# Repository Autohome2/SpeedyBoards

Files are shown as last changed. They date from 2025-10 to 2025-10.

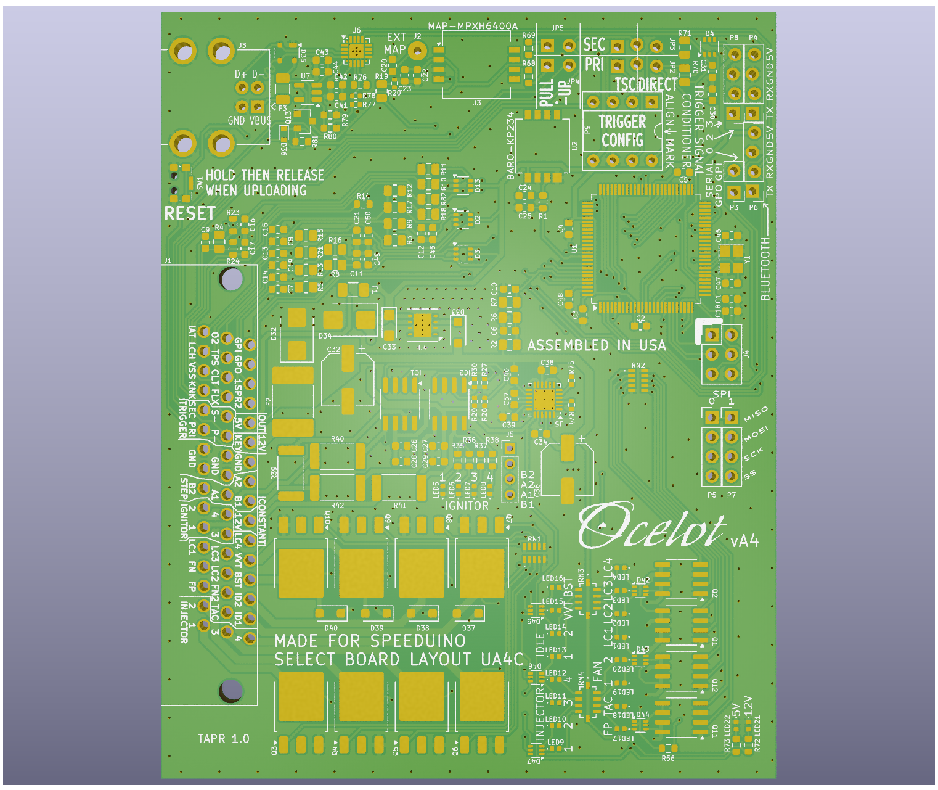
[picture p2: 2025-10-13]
OCELOT/Ocelot-vA4/RENDER/3D-Top.png

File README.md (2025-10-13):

# SpeedyBoards
WTMtronics has developed several EMS PCBs designed to use the Speeduino firmware.
The Speeduino code is available here [Speeduino](https://github.com/noisymime/speeduino), but the easiest way to load the code onto your ECU is to use [SpeedyLoader](https://github.com/speeduino/SpeedyLoader).
## Ocelot
The latest ECU designed by WTMtronics builds on the UA4C that came before it, and in fact if you compare the two side by side you will see many similarities. However there have been many improvements over the previous model which are outlined in the list below.
- Automotive connector
- Reduced size
- Integrated microcontroller
- VSS input
- Flyback diodes
- Reset button

The reset button was added as the only reset connection made to the microcontroller to prevent unwanted resets from USB connected devices. There is a caveat to this arrangement though. While the first time a firmware is loaded it will go on without intervention, subsequent times will require the user to hold the reset button down then release the button when the program starts the upload process. If the upload does not start right away go back and try again.

The Ocelot uses the Silicon Labs CP2102N USB to UART controller chip. Most modern computers will detect and automatically load a driver for the COM port. If you are not getting the COM port, then you can download drivers from their website [Silicon Labs Drivers](https://www.silabs.com/developers/usb-to-uart-bridge-vcp-drivers).

Versions:

A4:
- Corrected USB chip power
- Changed to smaller USB chip
- Corrected trigger labeling
- Changed trigger jumpers to match other boards

A3:
- First release

### Errata
vA3:
- Labeling for trigger jumpers is reversed. The secondary trigger jumpers are nearest the outside edge of the board, and the primary trigger jumpers are near the trigger conditioner socket.
- Serial numbers prior to 002287 will not operate with out a USB connection if no Bluetooth adapter is attached. If your serial number is 002287 or higher this issue does not affect your unit. If you are affected by this issue, please contact us so we can help you [WTMtronics Help](https://wtmtronics.com/help).
## UA4C
The Under Arduino Four Channel was designed to be as small as possible wile still using a standard off the shelf Arduino MEGA and Hammond extruded enclosure. This was achieved by using SMD components and placing the Arduino upside-down on top of the PCB. The unique stacking arrangement allows the unit to be particularly thin for a unit that still uses a separate Arduino MEGA. It is a 4+4 board that incorporates the follow features.
- Four injector channels
- Four ignitor channels
- Outputs for VVT, 2x PWM idle, boost, fuel pump, tachometer, and 2x fan
- Four auxiliary outputs
- Built in stepper idle control (versions C)
- Two trigger inputs
- Launch input
- Two additional interrupt input designated as flex and knock*
- Analog inputs for CLT, IAT, TPS, and O2
- Two auxiliary analog inputs
- MAP and baro sensor onboard
- Two GPIO connections that breakout inside the case

Latest version: C6

*Knock is currently unsupported in the firmware. Either input can be used for VSS.
## NO2C
The No Overhang Two Channel was designed to incorporate as many features as possible into a through-hole board that does not exceed the dimensions of the Arduino MEGA microcontroller it sits on top of. It is a 2+2 channel board that incorporates the features below.
- Two injector channels
- Two ignitor channels
- Outputs for VVT PWM idle, boost, fuel pump, and tachometer
- Two trigger inputs
- Launch input
- Analog inputs for CLT, IAT, TPS, and O2
- MAP sensor onboard
- Socket for stepper idle control module

Latest version: D1

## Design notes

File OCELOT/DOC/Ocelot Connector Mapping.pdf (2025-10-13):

All outputs (except ignitor and stepper idle) are ground switching. Connect at least two ground terminals to a single ground source.
Connector Terminal | Arduino Pin | Function
1 | | GPI | 25 | | STEPPER IDLE A1
2 | | GPO | 26 | D34 | IGNITOR 4
3 | A8 | SPARE INPUT 1 | 27 | D33 | IGNITOR 3
4 | A9 | SPARE INPUT 2 | 28 | D28 | LOW CURRENT OUTPUT 3
5 | | 5V OUT | 29 | D27 | LOW CURRENT OUTPUT 2
6 | | KEYED 12V INPUT | 30 | D25 | FAN 2
7 | | GROUND | 31 | D22 | TACHOMETER
8 | | STEPPER IDLE A2 | 32 | D6 | INJECTOR 3
9 | | STEPPER IDLE B1 | 33 | A5 | INLET AIR TEMPERATURE SENSOR
10 | | UNSWITCHED 12V INPUT (FLYBACK FOR IDLE, BOOST, VVT) | 34 | D37 | LAUNCH/CLUTCH
11 | D29 | LOW CURRENT OUTPUT 4 | 35 | D2 | VEHICLE SPEED SENSOR
12 | D11 | VVT | 36 | D21 | KNOCK SENSOR
13 | D12 | BOOST | 37 | D18 | SECONDARY TRIGGER
14 | D10 | PWM IDLE 2 | 38 | D19 | PRIMARY TRIGGER
15 | D9 | PWM IDLE 1 | 39 | | GROUND
16 | D5 | INJECTOR 4 | 40 | | GROUND
17 | A1 | EXHAUST GAS SENSOR | 41 | | STEPPER IDLE B2
18 | A3 | THROTTLE POSITION SENSOR | 42 | D36 | IGNITOR 2
19 | A4 | COOLANT TEMPERATURE SENSOR | 43 | D35 | IGNITOR 1
20 | D20 | FLEX FUEL SENSOR | 44 | D26 | LOW CURRENT OUTPUT 1
21 | | SECONDARY TRIGGER (VR- ONLY) | 45 | D24 | FAN 1
22 | | PRIMARY TRIGGER (VR- ONLY) | 46 | D23 | FUEL PUMP
23 | | GROUND | 47 | D7 | INJECTOR 2
24 | | GROUND | 48 | D8 | INJECTOR 1
1 | 2 | 3 | 4 | 5 | 6 | 7 | 8 | 9 | 10 | 11 | 12 | 13 | 14 | 15 | 16
17 | 18 | 19 | 20 | 21 | 22 | 23 | 24 | 25 | 26 | 27 | 28 | 29 | 30 | 31 | 32
33 | 34 | 35 | 36 | 37 | 38 | 39 | 40 | 41 | 42 | 43 | 44 | 45 | 46 | 47 | 48

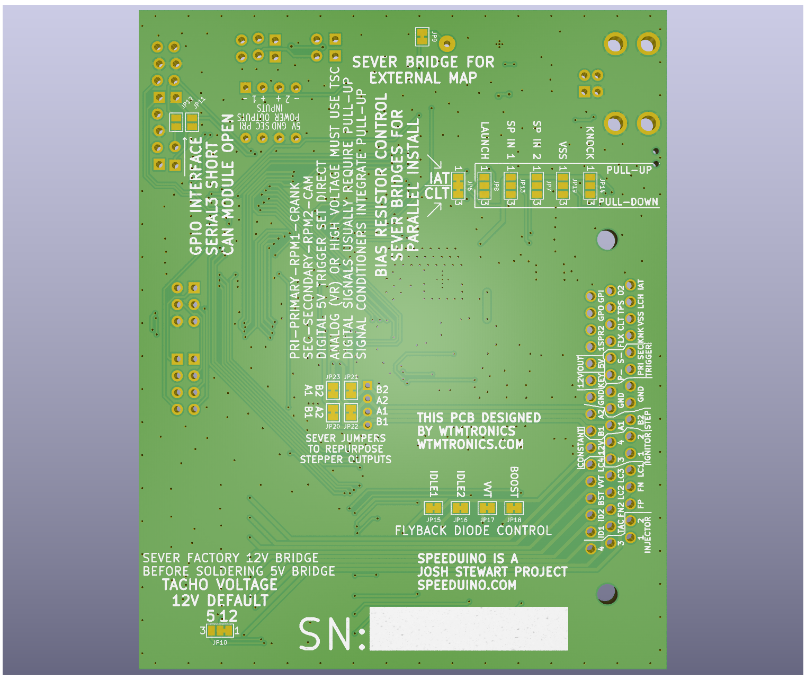
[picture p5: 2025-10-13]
OCELOT/Ocelot-vA4/RENDER/3D-Bottom.png

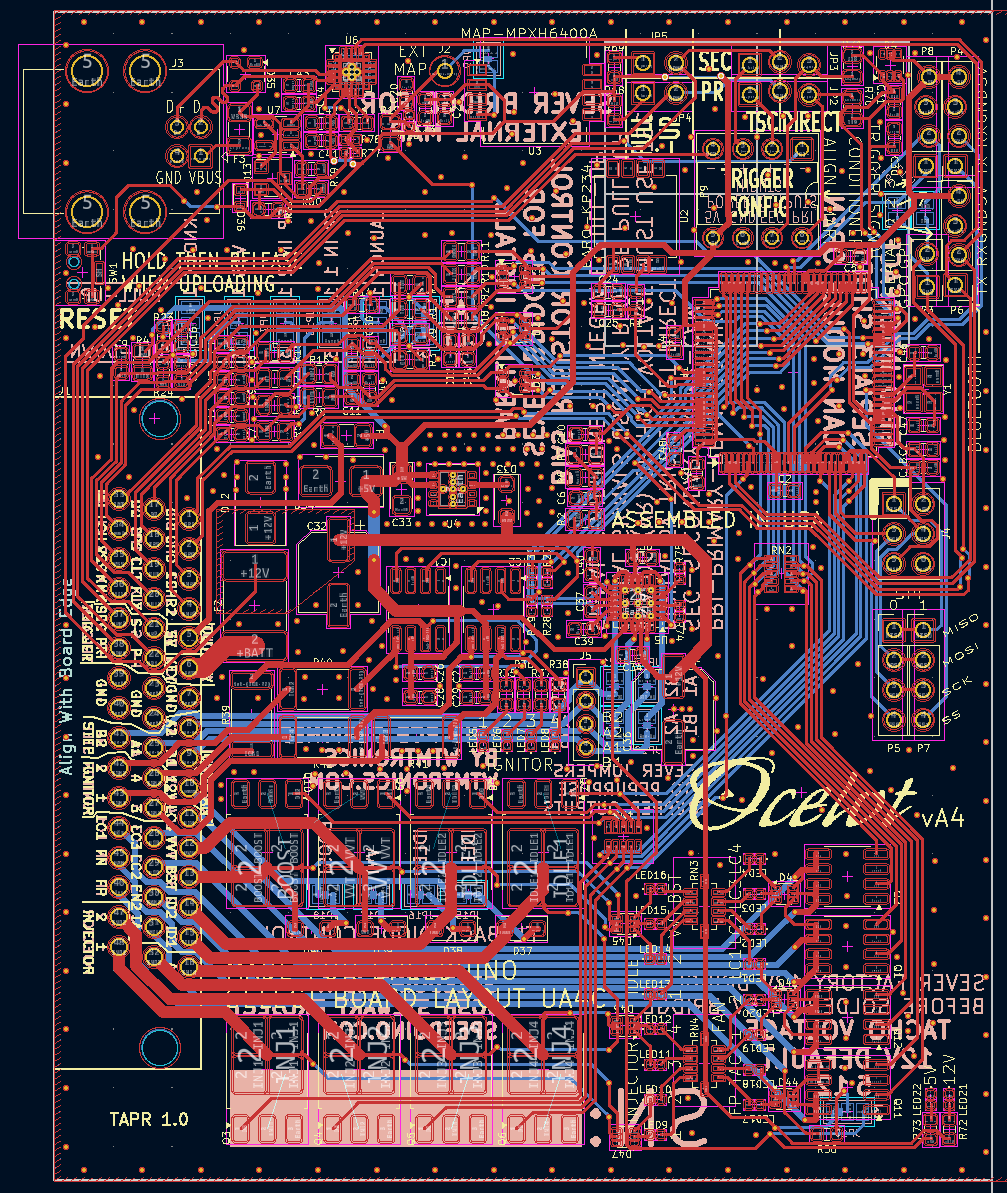
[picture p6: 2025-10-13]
OCELOT/Ocelot-vA4/RENDER/CAD.png

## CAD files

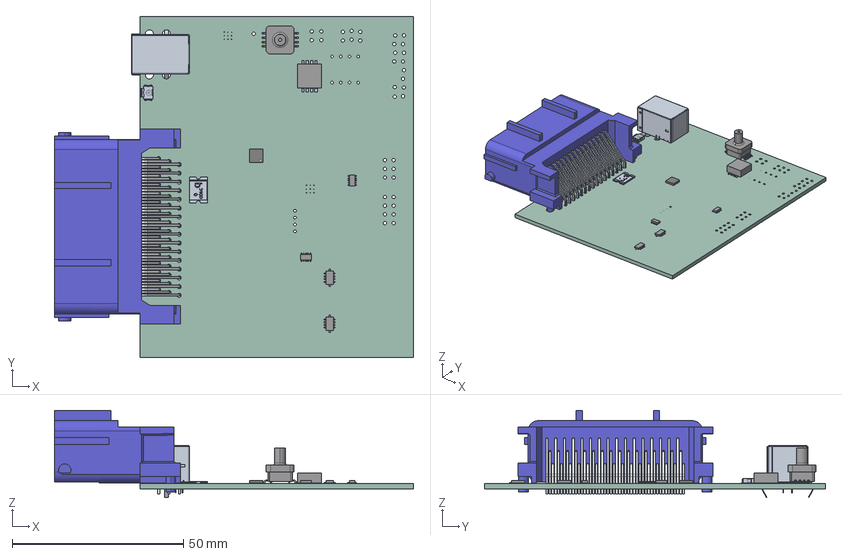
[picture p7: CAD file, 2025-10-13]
OCELOT/Ocelot-vA3/Ocelot-vA3.step
105.0 x 99.8 x 25.5 mm
MPXH6400AC6T1
100-60 v1
WSON8_4x4mm_Pitch08mm
HPppfj48PAZu_100525
ASSEMBLY x 5
OCELOT-vA3_PCB

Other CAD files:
OCELOT/Ocelot-vA3/ocelot.step

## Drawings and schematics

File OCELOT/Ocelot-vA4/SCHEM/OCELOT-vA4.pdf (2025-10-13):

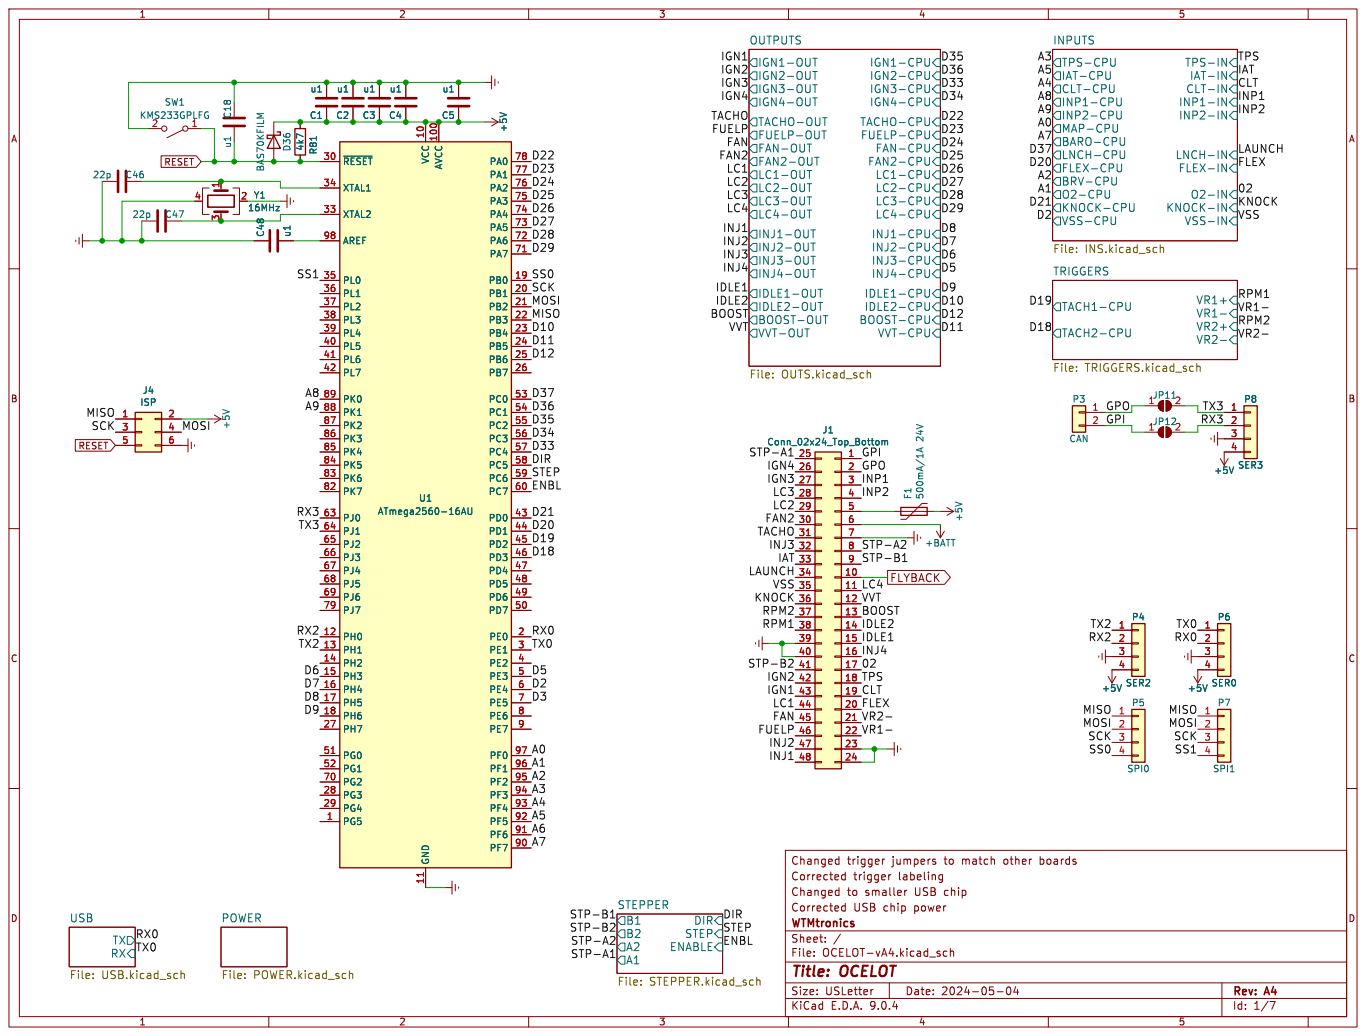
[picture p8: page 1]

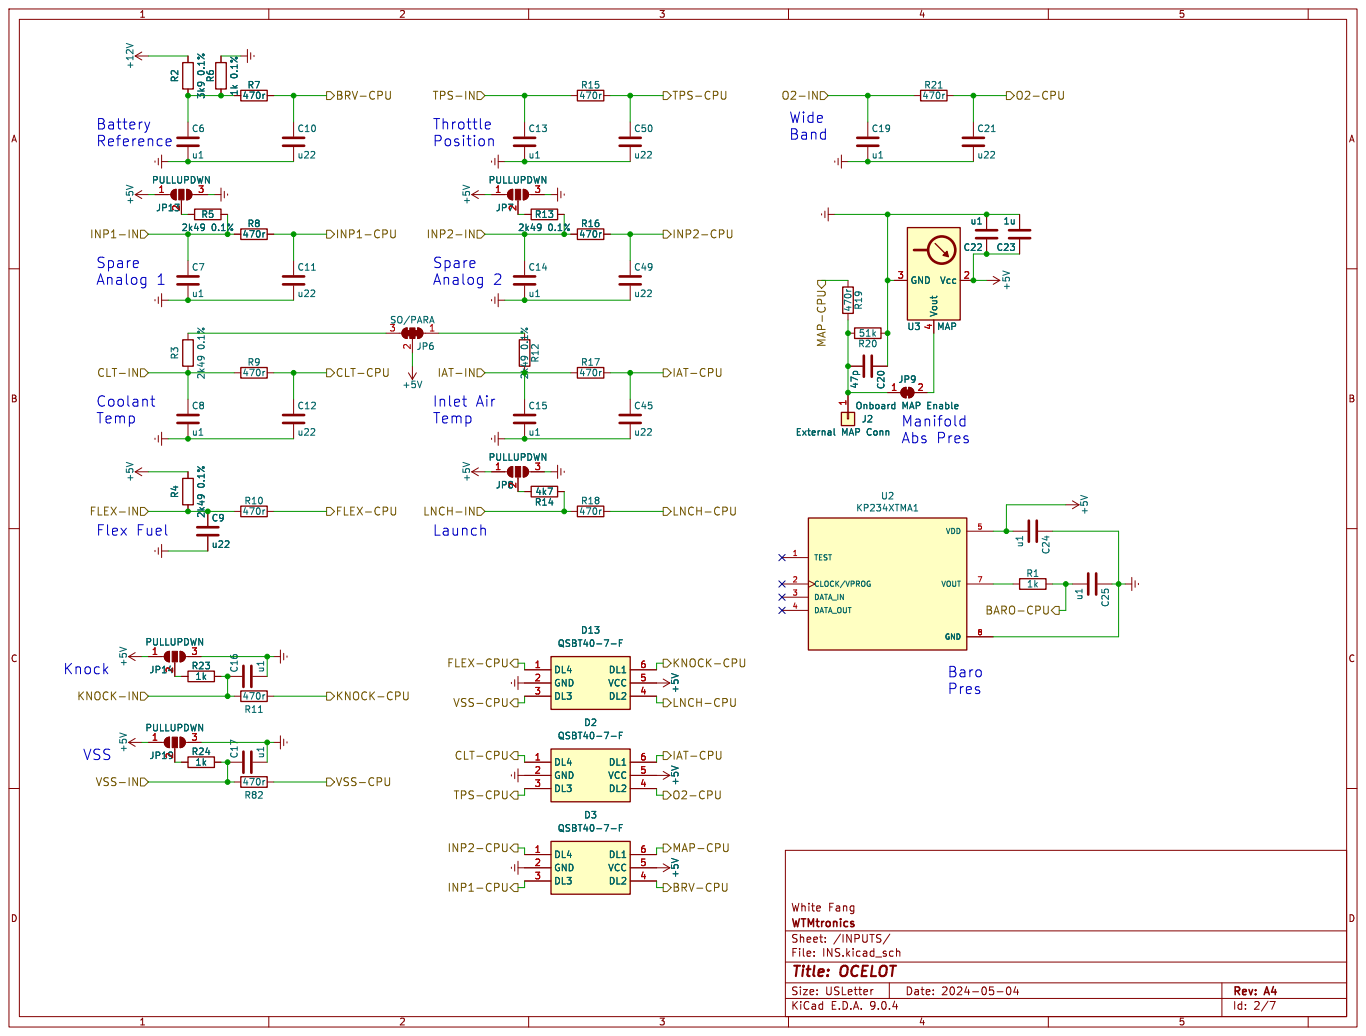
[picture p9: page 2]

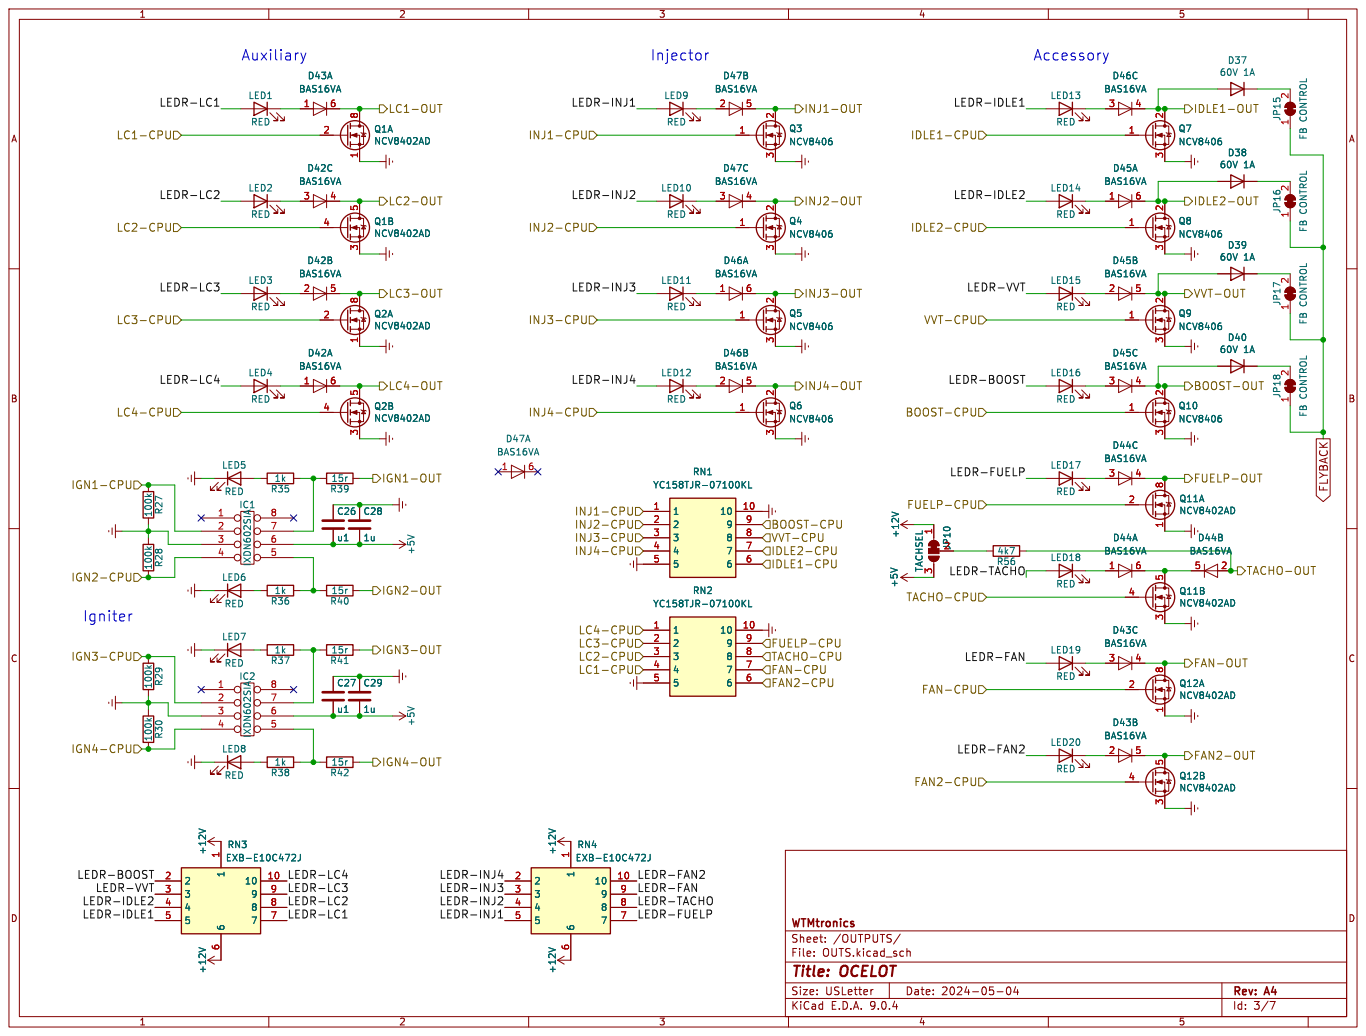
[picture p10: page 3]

File: OUTS.kicad_sch Sheet: /OUTPUTS/ WTMtronics

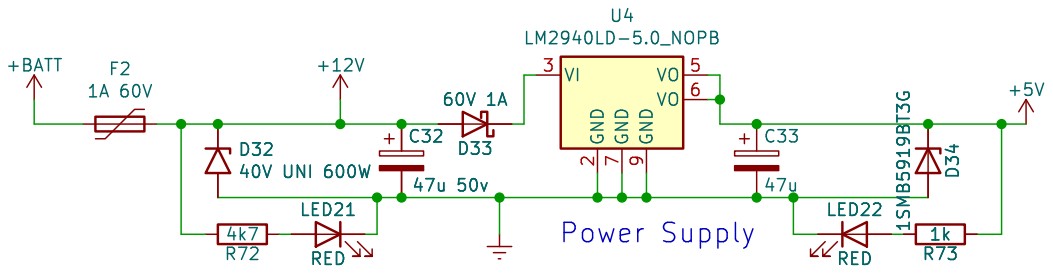
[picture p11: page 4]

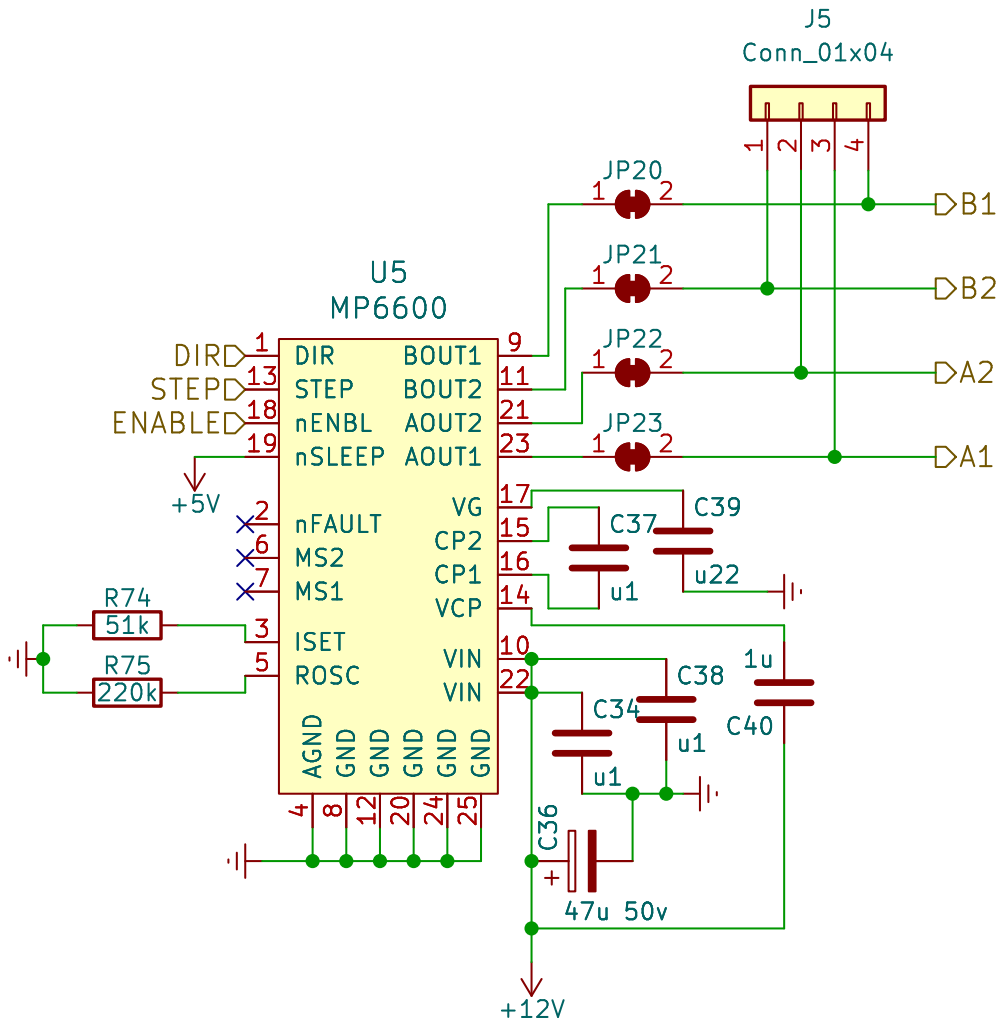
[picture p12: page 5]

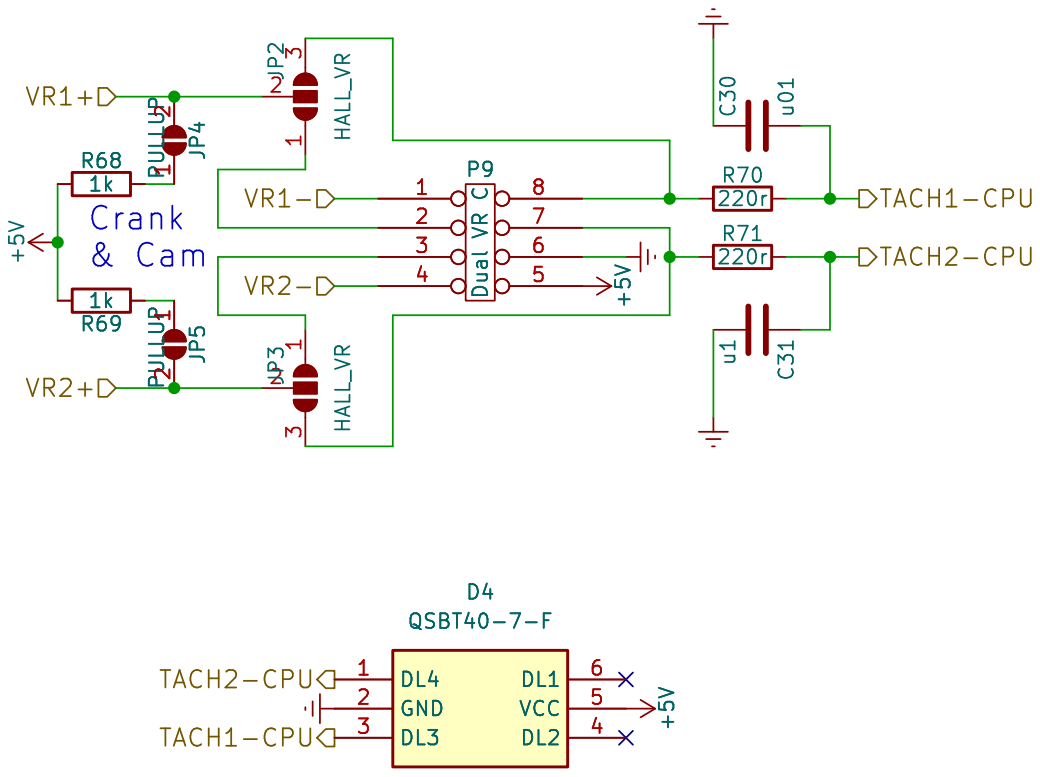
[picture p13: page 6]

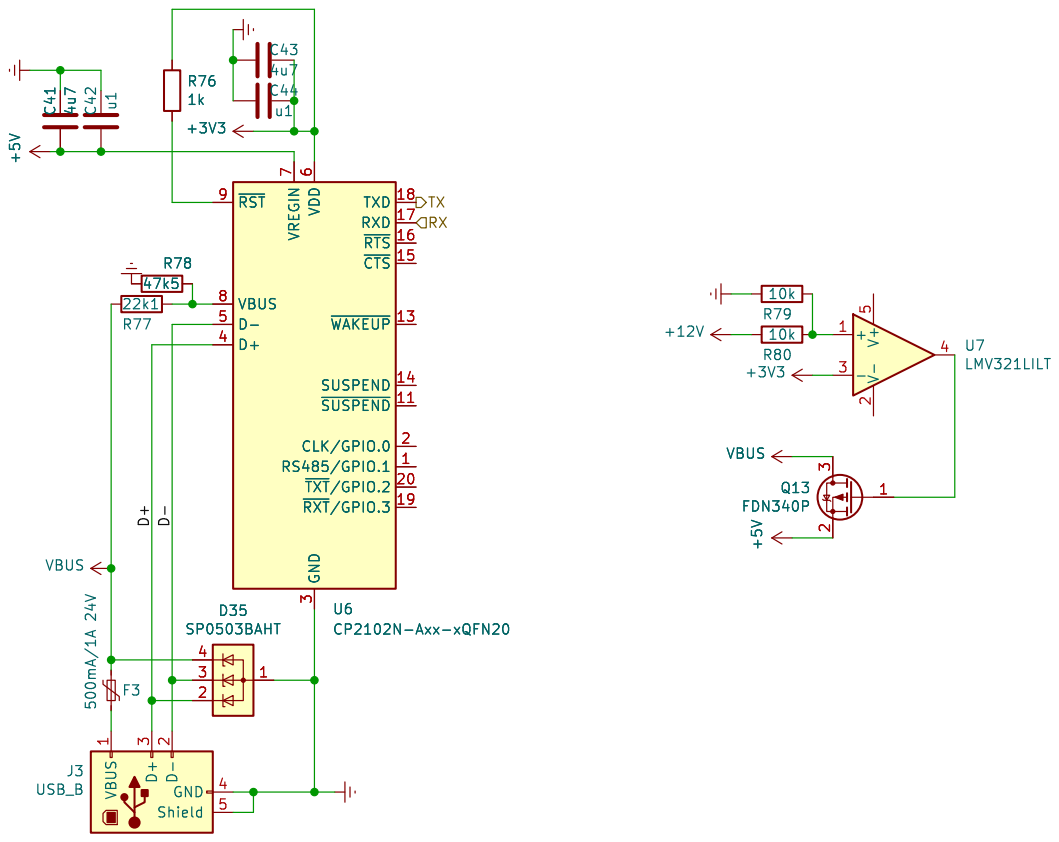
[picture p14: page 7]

File: USB.kicad_sch Sheet: /USB/ WTMtronics

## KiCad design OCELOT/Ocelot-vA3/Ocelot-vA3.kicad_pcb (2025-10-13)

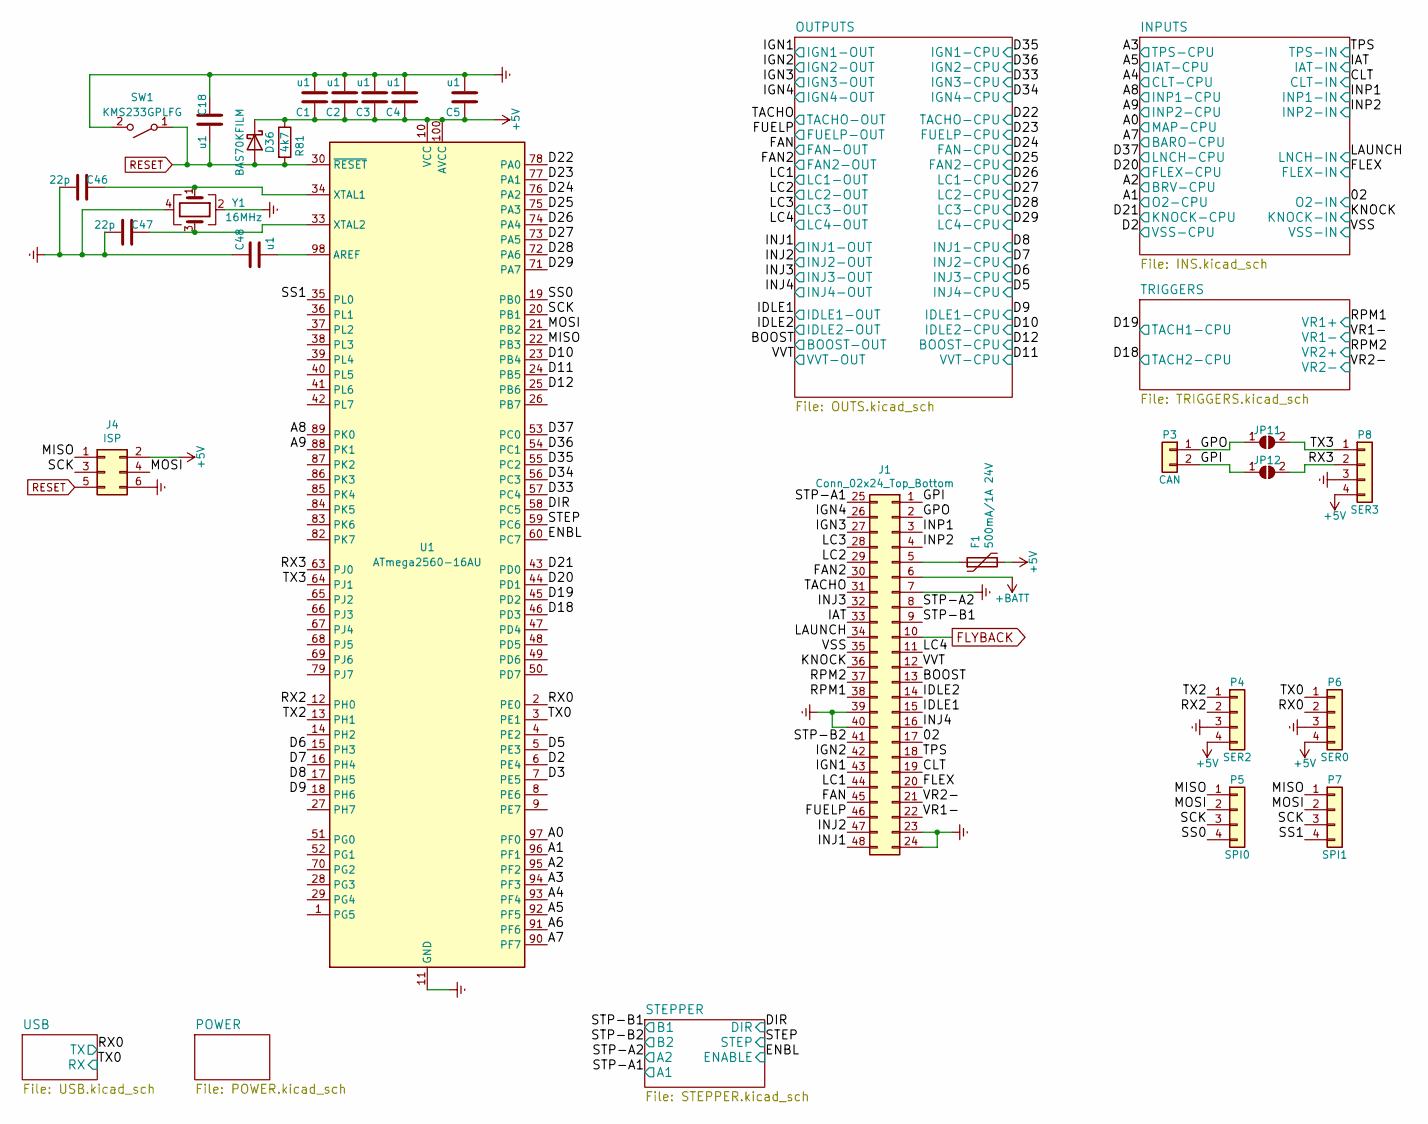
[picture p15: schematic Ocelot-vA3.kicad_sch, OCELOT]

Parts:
C1, C2, C3, C4, C5, C18, C48: u1; C_0603_1608Metric; MPN CL21B104KBFNNNE
C46, C47: 22p; C_0603_1608Metric
D36: BAS70KFILM; D_SOD-523; MPN BAS70-02V-V-G-08
F1: 500mA/1A 24V; Fuse_1206_3216Metric; MPN 0ZCJ0050AF2E
J1: Conn_02x24_Top_Bottom; JSA_ZRO_48_Black
J4: ISP; PinHeader_2x03_P2.54mm_Vertical
JP11, JP12: SolderJumper_2_Open; SolderJumper-2_P1.3mm_Open_Pad1.0x1.5mm; MPN DNP
P3: CAN; PinHeader_1x02_P2.54mm_Vertical; MPN DNP
P4: SER2; Pin_Header_Straight_1x04_Pitch2.54mm; MPN DNP
P5: SPI0; Pin_Header_Straight_1x04_Pitch2.54mm; MPN DNP
P6: SER0; Pin_Header_Straight_1x04_Pitch2.54mm; MPN DNP
P7: SPI1; Pin_Header_Straight_1x04_Pitch2.54mm; MPN DNP
P8: SER3; Pin_Header_Straight_1x04_Pitch2.54mm; MPN DNP
R81: 4k7; R_0603_1608Metric
SW1: KMS233GPLFG; SW_SPST_CK_KMS2xxGP
U1: ATmega2560-16AU; TQFP-100_14x14mm_P0.5mm
Y1: 16MHz; Crystal_SMD_3225-4Pin_3.2x2.5mm; MPN YSX321SL

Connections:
+5V: C1.1, C2.1, C3.1, C4.1, C5.1, D36.1 (K), F1.2, J4.2, P4.4, P6.4, P8.4, R81.1, U1.10 (VCC), U1.31 (VCC), U1.61 (VCC), U1.80 (VCC), U1.100 (AVCC); also elsewhere on the board
+BATT: J1.6; also elsewhere on the board
/02: J1.17; also elsewhere on the board
/A0: U1.97 (PF0); also elsewhere on the board
/A1: U1.96 (PF1); also elsewhere on the board
/A2: U1.95 (PF2); also elsewhere on the board
/A3: U1.94 (PF3); also elsewhere on the board
/A4: U1.93 (PF4); also elsewhere on the board
/A5: U1.92 (PF5); also elsewhere on the board
/A6: U1.91 (PF6)
/A7: U1.90 (PF7); also elsewhere on the board
/A8: U1.89 (PK0); also elsewhere on the board
/A9: U1.88 (PK1); also elsewhere on the board
/BOOST: J1.13; also elsewhere on the board
/CLT: J1.19; also elsewhere on the board
/D2: U1.6 (PE4); also elsewhere on the board
/D3: U1.7 (PE5)
/D5: U1.5 (PE3); also elsewhere on the board
/D6: U1.15 (PH3); also elsewhere on the board
/D7: U1.16 (PH4); also elsewhere on the board
/D8: U1.17 (PH5); also elsewhere on the board
/D9: U1.18 (PH6); also elsewhere on the board
/D10: U1.23 (PB4); also elsewhere on the board
/D11: U1.24 (PB5); also elsewhere on the board
/D12: U1.25 (PB6); also elsewhere on the board
/D18: U1.46 (PD3); also elsewhere on the board
/D19: U1.45 (PD2); also elsewhere on the board
/D20: U1.44 (PD1); also elsewhere on the board
/D21: U1.43 (PD0); also elsewhere on the board
/D22: U1.78 (PA0); also elsewhere on the board
/D23: U1.77 (PA1); also elsewhere on the board
/D24: U1.76 (PA2); also elsewhere on the board
/D25: U1.75 (PA3); also elsewhere on the board
/D26: U1.74 (PA4); also elsewhere on the board
/D27: U1.73 (PA5); also elsewhere on the board
/D28: U1.72 (PA6); also elsewhere on the board
/D29: U1.71 (PA7); also elsewhere on the board
/D33: U1.57 (PC4); also elsewhere on the board
/D34: U1.56 (PC3); also elsewhere on the board
/D35: U1.55 (PC2); also elsewhere on the board
/D36: U1.54 (PC1); also elsewhere on the board
/D37: U1.53 (PC0); also elsewhere on the board
/DIR: U1.58 (PC5); also elsewhere on the board
/ENBL: U1.60 (PC7); also elsewhere on the board
/FAN: J1.45; also elsewhere on the board
/FAN2: J1.30; also elsewhere on the board
/FLEX: J1.20; also elsewhere on the board
/FUELP: J1.46; also elsewhere on the board
/GPI: J1.1, JP12.1 (A), P3.2
/GPO: J1.2, JP11.1 (A), P3.1
/IAT: J1.33; also elsewhere on the board
/IDLE1: J1.15; also elsewhere on the board
/IDLE2: J1.14; also elsewhere on the board
/IGN1: J1.43; also elsewhere on the board
/IGN2: J1.42; also elsewhere on the board
/IGN3: J1.27; also elsewhere on the board
/IGN4: J1.26; also elsewhere on the board
/INJ1: J1.48; also elsewhere on the board
/INJ2: J1.47; also elsewhere on the board
/INJ3: J1.32; also elsewhere on the board
/INJ4: J1.16; also elsewhere on the board
/INP1: J1.3; also elsewhere on the board
/INP2: J1.4; also elsewhere on the board
/KNOCK: J1.36; also elsewhere on the board
/LAUNCH: J1.34; also elsewhere on the board
/LC1: J1.44; also elsewhere on the board
/LC2: J1.29; also elsewhere on the board
/LC3: J1.28; also elsewhere on the board
/LC4: J1.11; also elsewhere on the board
/MISO: J4.1, P5.1, P7.1, U1.22 (PB3)
/MOSI: J4.4, P5.2, P7.2, U1.21 (PB2)
/RPM1: J1.38; also elsewhere on the board
/RPM2: J1.37; also elsewhere on the board
/RX0: P6.2, U1.2 (PE0); also elsewhere on the board
/RX2: P4.2, U1.12 (PH0)
/RX3: JP12.2 (B), P8.2, U1.63 (PJ0)
/SCK: J4.3, P5.3, P7.3, U1.20 (PB1)
/SS0: P5.4, U1.19 (PB0)
/SS1: P7.4, U1.35 (PL0)
/STEP: U1.59 (PC6); also elsewhere on the board
/STP-A1: J1.25; also elsewhere on the board
/STP-A2: J1.8; also elsewhere on the board
/STP-B1: J1.9; also elsewhere on the board
/STP-B2: J1.41; also elsewhere on the board
/TACHO: J1.31; also elsewhere on the board
/TPS: J1.18; also elsewhere on the board
/TX0: P6.1, U1.3 (PE1); also elsewhere on the board
/TX2: P4.1, U1.13 (PH1)
/TX3: JP11.2 (B), P8.1, U1.64 (PJ1)
/VR1-: J1.22; also elsewhere on the board
/VR2-: J1.21; also elsewhere on the board
/VSS: J1.35; also elsewhere on the board
/VVT: J1.12; also elsewhere on the board
Earth: C1.2, C2.2, C3.2, C4.2, C5.2, C18.1, C46.2, C47.1, C48.1, J1.7, J1.23, J1.24, J1.39, J1.40, J4.6, P4.3, P6.3, P8.3, SW1.2 (B), U1.11 (GND), U1.32 (GND), U1.62 (GND), U1.81 (GND), U1.99 (GND), Y1.2, Y1.4; also elsewhere on the board
FLYBACK: J1.10; also elsewhere on the board
unnamed: F1.1, J1.5
unnamed: C48.2, U1.98 (AREF)
unnamed: C46.1, U1.34 (XTAL1), Y1.1
unnamed: C47.2, U1.33 (XTAL2), Y1.3
RESET: C18.2, D36.2 (A), J4.5, R81.2, SW1.1 (A), U1.30 (~RESET)

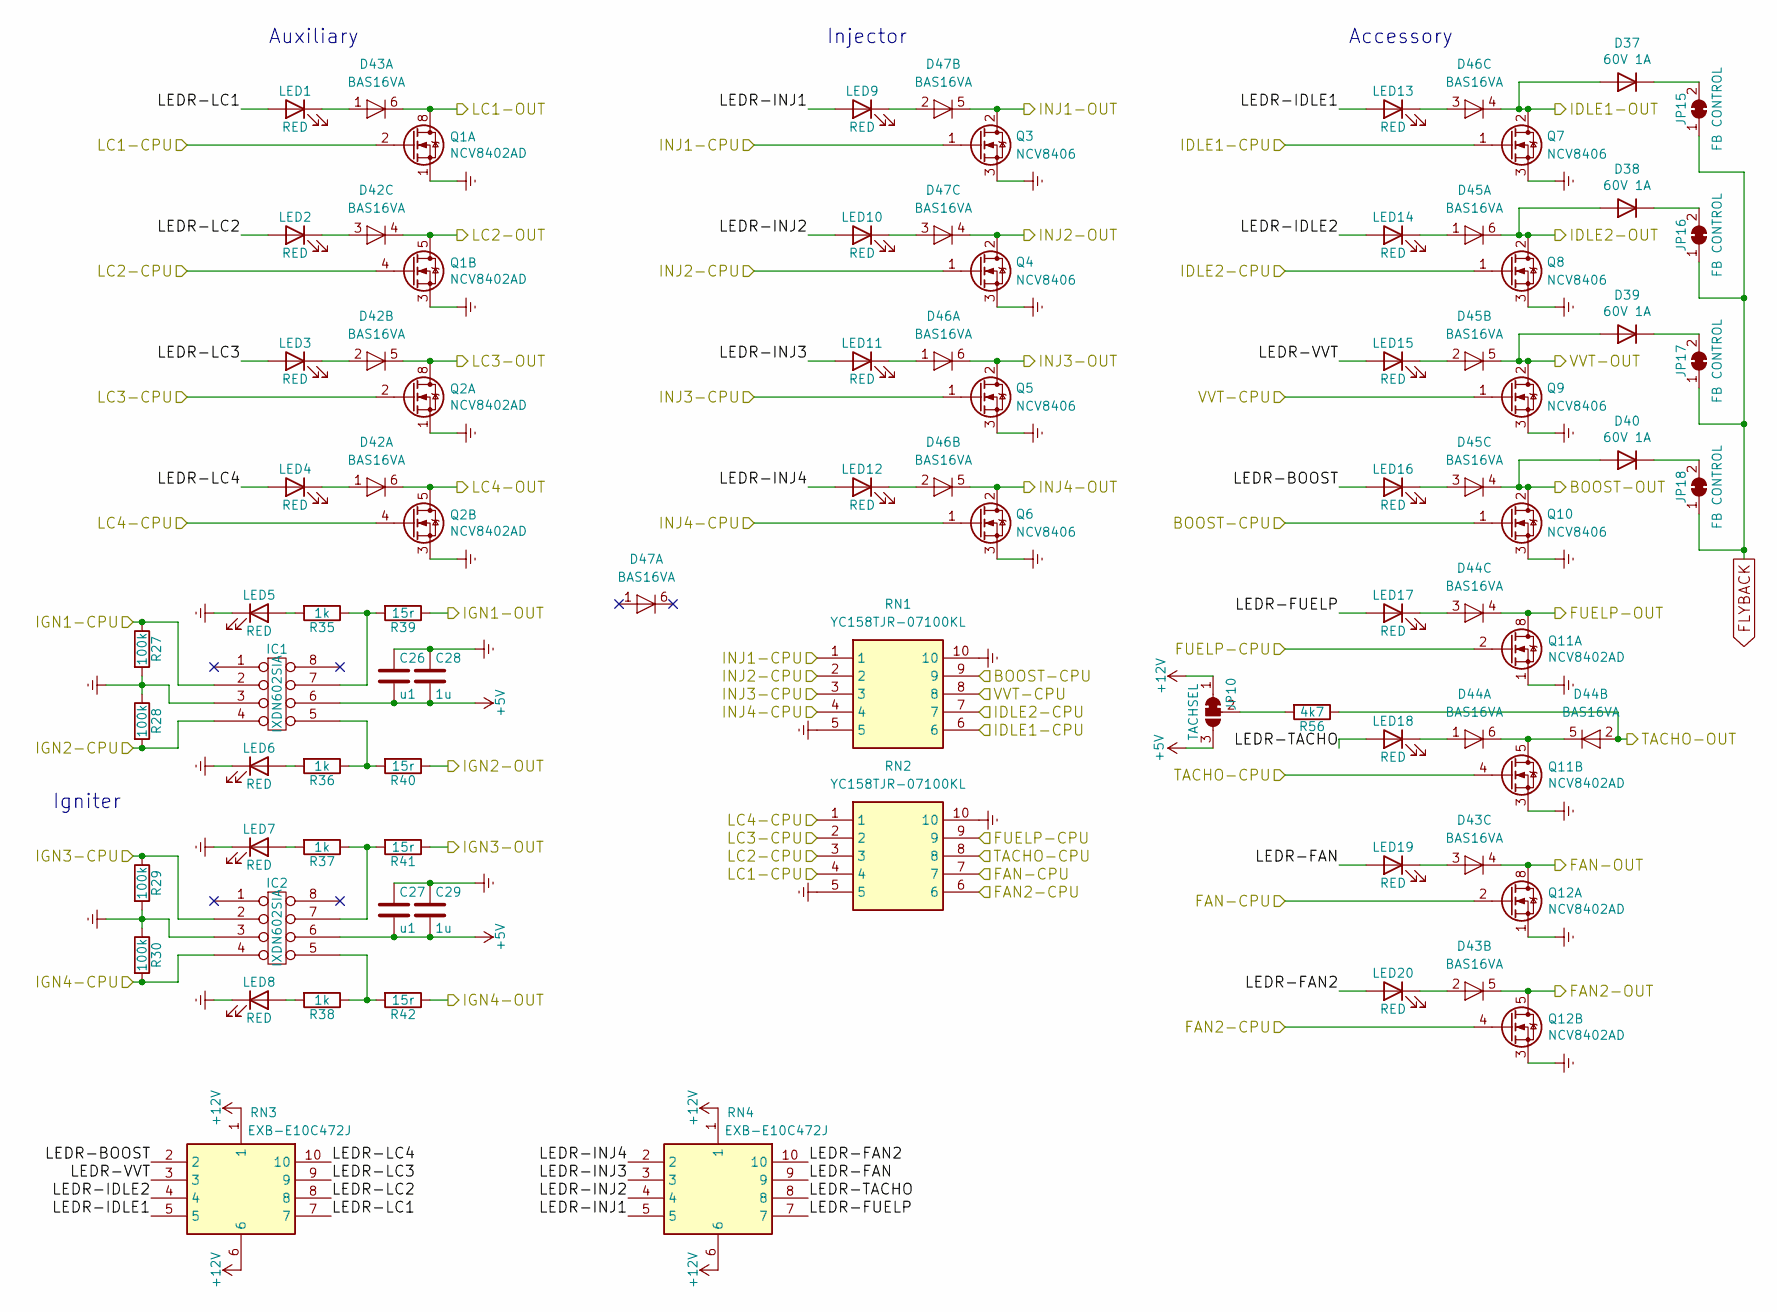
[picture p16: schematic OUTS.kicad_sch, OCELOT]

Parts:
C26, C27: u1; C_0603_1608Metric; MPN CL21B104KBFNNNE
C28, C29: 1u; C_0603_1608Metric; MPN CL21B105KBFNNNE
D37, D38, D39, D40: 60V 1A; D_SOD-123F
D42, D43, D44, D45, D46, D47: BAS16VA; SOT-563
IC1, IC2: IXDN602SIA; SOIC-8_3.9x4.9mm_P1.27mm; MPN IXDN602SIA
JP10: TACHSEL; SolderJumper-3_P1.3mm_Bridged12_Pad1.0x1.5mm_NumberLabels; MPN DNP
JP15, JP16, JP17, JP18: FB CONTROL; SolderJumper-2_P1.3mm_Bridged_Pad1.0x1.5mm; MPN DNP
LED1, LED2, LED3, LED4, LED5, LED6, LED7, LED8, LED9, LED10, LED11, LED12, LED13, LED14, LED15, LED16, LED17, LED18, LED19, LED20: RED; LED_0402_1005Metric; MPN SML-310LTT86
Q1, Q2, Q11, Q12: NCV8402AD; SOIC-8_3.9x4.9mm_P1.27mm; MPN NCV8402ADDR2G
Q3, Q4, Q5, Q6, Q7, Q8, Q9, Q10: NCV8406; TO-252-3_TabPin2; MPN NCV8406BDTRKG
R27, R28, R29, R30: 100k; R_0402_1005Metric; MPN RK73B1JTTD104J
R35, R36, R37, R38: 1k; R_0603_1608Metric; MPN RK73H2ATTD4700F
R39, R40, R41, R42: 15r; R_2512_6332Metric; MPN RK73H3ATTE15R0F
R56: 4k7; R_0603_1608Metric
RN1, RN2: YC158TJR-07100KL; YC158TJR07100KL; Manufacturer_Part_Number YC158TJR-07100KL
RN3, RN4: EXB-E10C472J; EXBE10C473J; Manufacturer_Part_Number EXB-E10C473J; Mouser Part Number 667-EXB-E10C473J

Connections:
+5V: C26.2, C27.2, C28.2, C29.2, IC1.6, IC2.6, JP10.3 (B); also elsewhere on the board
+12V: JP10.1 (A), RN3.1, RN3.6, RN4.1, RN4.6; also elsewhere on the board
/BOOST: D40.2 (A), D45.4 (K), Q10.2 (D); also elsewhere on the board
/D5: Q6.1 (G), RN1.4; also elsewhere on the board
/D6: Q5.1 (G), RN1.3; also elsewhere on the board
/D7: Q4.1 (G), RN1.2; also elsewhere on the board
/D8: Q3.1 (G), RN1.1; also elsewhere on the board
/D9: Q7.1 (G), RN1.6; also elsewhere on the board
/D10: Q8.1 (G), RN1.7; also elsewhere on the board
/D11: Q9.1 (G), RN1.8; also elsewhere on the board
/D12: Q10.1 (G), RN1.9; also elsewhere on the board
/D22: Q11.4 (G2), RN2.8; also elsewhere on the board
/D23: Q11.2 (G1), RN2.9; also elsewhere on the board
/D24: Q12.2 (G1), RN2.7; also elsewhere on the board
/D25: Q12.4 (G2), RN2.6; also elsewhere on the board
/D26: Q1.2 (G1), RN2.4; also elsewhere on the board
/D27: Q1.4 (G2), RN2.3; also elsewhere on the board
/D28: Q2.2 (G1), RN2.2; also elsewhere on the board
/D29: Q2.4 (G2), RN2.1; also elsewhere on the board
/D33: IC2.2, R29.1; also elsewhere on the board
/D34: IC2.4, R30.2; also elsewhere on the board
/D35: IC1.2, R27.1; also elsewhere on the board
/D36: IC1.4, R28.2; also elsewhere on the board
/FAN: D43.4 (K), Q12.7 (D1), Q12.8 (D1); also elsewhere on the board
/FAN2: D43.5 (K), Q12.5 (D2), Q12.6 (D2); also elsewhere on the board
/FUELP: D44.4 (K), Q11.7 (D1), Q11.8 (D1); also elsewhere on the board
/IDLE1: D37.2 (A), D46.4 (K), Q7.2 (D); also elsewhere on the board
/IDLE2: D38.2 (A), D45.6 (K), Q8.2 (D); also elsewhere on the board
/IGN1: R39.1; also elsewhere on the board
/IGN2: R40.1; also elsewhere on the board
/IGN3: R41.1; also elsewhere on the board
/IGN4: R42.1; also elsewhere on the board
/INJ1: D47.5 (K), Q3.2 (D); also elsewhere on the board
/INJ2: D47.4 (K), Q4.2 (D); also elsewhere on the board
/INJ3: D46.6 (K), Q5.2 (D); also elsewhere on the board
/INJ4: D46.5 (K), Q6.2 (D); also elsewhere on the board
/LC1: D43.6 (K), Q1.7 (D1), Q1.8 (D1); also elsewhere on the board
/LC2: D42.4 (K), Q1.5 (D2), Q1.6 (D2); also elsewhere on the board
/LC3: D42.5 (K), Q2.7 (D1), Q2.8 (D1); also elsewhere on the board
/LC4: D42.6 (K), Q2.5 (D2), Q2.6 (D2); also elsewhere on the board
/OUTPUTS/LEDR-BOOST: LED16.2 (A), RN3.2
/OUTPUTS/LEDR-FAN: LED19.2 (A), RN4.9
/OUTPUTS/LEDR-FAN2: LED20.2 (A), RN4.10
/OUTPUTS/LEDR-FUELP: LED17.2 (A), RN4.7
/OUTPUTS/LEDR-IDLE1: LED13.2 (A), RN3.5
/OUTPUTS/LEDR-IDLE2: LED14.2 (A), RN3.4
/OUTPUTS/LEDR-INJ1: LED9.2 (A), RN4.5
/OUTPUTS/LEDR-INJ2: LED10.2 (A), RN4.4
/OUTPUTS/LEDR-INJ3: LED11.2 (A), RN4.3
/OUTPUTS/LEDR-INJ4: LED12.2 (A), RN4.2
/OUTPUTS/LEDR-LC1: LED1.2 (A), RN3.7
/OUTPUTS/LEDR-LC2: LED2.2 (A), RN3.8
/OUTPUTS/LEDR-LC3: LED3.2 (A), RN3.9
/OUTPUTS/LEDR-LC4: LED4.2 (A), RN3.10
/OUTPUTS/LEDR-TACHO: LED18.2 (A), RN4.8
/OUTPUTS/LEDR-VVT: LED15.2 (A), RN3.3
/TACHO: D44.2 (A), R56.1; also elsewhere on the board
/VVT: D39.2 (A), D45.5 (K), Q9.2 (D); also elsewhere on the board
Earth: C26.1, C27.1, C28.1, C29.1, IC1.3, IC2.3, LED5.1 (K), LED6.1 (K), LED7.1 (K), LED8.1 (K), Q1.1 (S1), Q1.3 (S2), Q2.1 (S1), Q2.3 (S2), Q3.3 (S), Q4.3 (S), Q5.3 (S), Q6.3 (S), Q7.3 (S), Q8.3 (S), Q9.3 (S), Q10.3 (S), Q11.1 (S1), Q11.3 (S2), Q12.1 (S1), Q12.3 (S2), R27.2, R28.1, R29.2, R30.1, RN1.5, RN1.10, RN2.5, RN2.10; also elsewhere on the board
FLYBACK: JP15.1 (A), JP16.1 (A), JP17.1 (A), JP18.1 (A); also elsewhere on the board
unnamed: D37.1 (K), JP15.2 (B)
unnamed: D38.1 (K), JP16.2 (B)
unnamed: D39.1 (K), JP17.2 (B)
unnamed: D40.1 (K), JP18.2 (B)
unnamed: D42.1 (A), LED4.1 (K)
unnamed: D42.2 (A), LED3.1 (K)
unnamed: D42.3 (A), LED2.1 (K)
unnamed: D43.1 (A), LED1.1 (K)
unnamed: D43.2 (A), LED20.1 (K)
unnamed: D43.3 (A), LED19.1 (K)
unnamed: D44.1 (A), LED18.1 (K)
unnamed: D44.5 (K), D44.6 (K), Q11.5 (D2), Q11.6 (D2)
unnamed: D44.3 (A), LED17.1 (K)
unnamed: D45.1 (A), LED14.1 (K)
unnamed: D45.2 (A), LED15.1 (K)
unnamed: D45.3 (A), LED16.1 (K)
unnamed: D46.1 (A), LED11.1 (K)
unnamed: D46.2 (A), LED12.1 (K)
unnamed: D46.3 (A), LED13.1 (K)
unnamed: D47.2 (A), LED9.1 (K)
unnamed: D47.3 (A), LED10.1 (K)
unnamed: IC1.5, R36.1, R40.2
unnamed: IC1.7, R35.1, R39.2
unnamed: IC2.5, R38.1, R42.2
unnamed: IC2.7, R37.1, R41.2
unnamed: JP10.2 (C), R56.2
unnamed: LED5.2 (A), R35.2
unnamed: LED6.2 (A), R36.2
unnamed: LED7.2 (A), R37.2
unnamed: LED8.2 (A), R38.2

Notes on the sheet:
Auxiliary
Injector
Accessory
Igniter

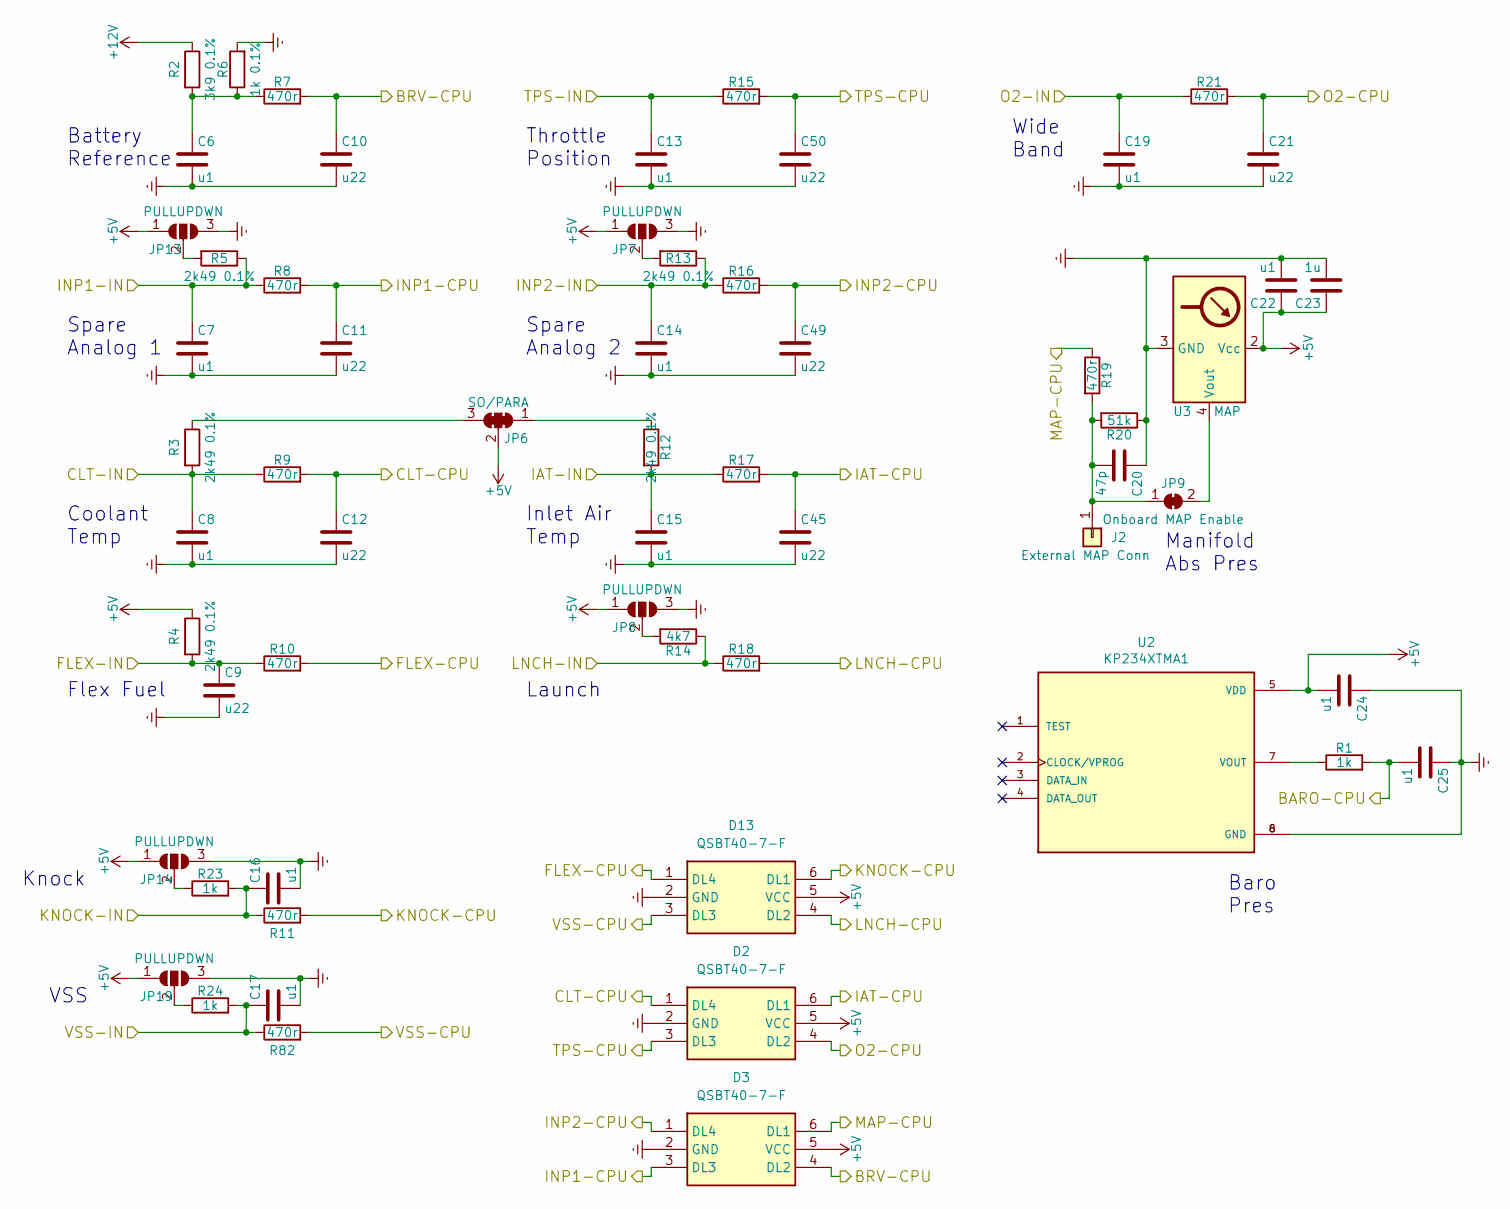
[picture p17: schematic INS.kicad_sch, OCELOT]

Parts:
C6, C7, C8, C13, C14, C15, C16, C17, C19, C22, C24, C25: u1; C_0603_1608Metric; MPN CL21B104KBFNNNE
C9, C10, C11, C12, C21, C45, C49, C50: u22; C_0603_1608Metric; MPN CL21B224KBFNNNE
C20: 47p; C_0603_1608Metric; MPN CL21C470JBANNNC
C23: 1u; C_0603_1608Metric; MPN CL21B105KBFNNNE
D2, D3, D13: QSBT40-7-F; SOT-363_SC-70-6; Mouser Part Number 621-QSBT40-F
J2: External MAP Conn; SolderWirePad_single_1mmDrill; MPN DNP
JP6: SO/PARA; SolderJumper-3_P1.3mm_Bridged123_Pad1.0x1.5mm_NumberLabels; MPN DNP
JP7, JP8, JP13, JP14, JP19: PULLUPDWN; SolderJumper-3_P1.3mm_Open_Pad1.0x1.5mm_NumberLabels; MPN DNP
JP9: Onboard MAP Enable; SolderJumper-2_P1.3mm_Bridged_Pad1.0x1.5mm; MPN DNP
R1, R23, R24: 1k; R_0603_1608Metric; MPN RK73H2ATTD1001F
R2: 3k9 0.1%; R_0805_2012Metric; MPN ERA6AEB392V
R3, R4, R5, R12, R13: 2k49 0.1%; R_0805_2012Metric; MPN ERA6AEB2491V
R6: 1k 0.1%; R_0805_2012Metric; MPN ERA6AEB102V
R7, R8, R9, R10, R11, R15, R16, R17, R18, R19, R21, R82: 470r; R_0805_2012Metric; MPN RK73H2ATTD4700F
R14: 4k7; R_0603_1608Metric
R20: 51k; R_0402_1005Metric; MPN RK73H2ATTD5102F
U2: KP234XTMA1; XDCR_KP234XTMA1; PARTREV 1.0
U3: MAP; Freescale_98ARH99089A; MPN MPXH6400AC6U

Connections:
+5V: C22.1, C23.1, C24.2, D2.5 (VCC), D3.5 (VCC), D13.5 (VCC), JP6.2 (C), JP7.1 (A), JP8.1 (A), JP13.1 (A), JP14.1 (A), JP19.1 (A), R4.1, U2.5 (VDD), U3.2 (Vcc); also elsewhere on the board
+12V: R2.1; also elsewhere on the board
/02: C19.1, R21.1; also elsewhere on the board
/A0: D3.6 (DL1), R19.1; also elsewhere on the board
/A1: C21.1, D2.4 (DL2), R21.2; also elsewhere on the board
/A2: C10.1, D3.4 (DL2), R7.2; also elsewhere on the board
/A3: C50.1, D2.3 (DL3), R15.2; also elsewhere on the board
/A4: C12.1, D2.1 (DL4), R9.2; also elsewhere on the board
/A5: C45.1, D2.6 (DL1), R17.2; also elsewhere on the board
/A7: C25.2, R1.2; also elsewhere on the board
/A8: C11.1, D3.3 (DL3), R8.2; also elsewhere on the board
/A9: C49.1, D3.1 (DL4), R16.2; also elsewhere on the board
/CLT: C8.1, R3.2, R9.1; also elsewhere on the board
/D2: D13.3 (DL3), R82.2; also elsewhere on the board
/D20: D13.1 (DL4), R10.2; also elsewhere on the board
/D21: D13.6 (DL1), R11.2; also elsewhere on the board
/D37: D13.4 (DL2), R18.2; also elsewhere on the board
/FLEX: C9.1, R4.2, R10.1; also elsewhere on the board
/IAT: C15.1, R12.2, R17.1; also elsewhere on the board
/INP1: C7.1, R5.1, R8.1; also elsewhere on the board
/INP2: C14.1, R13.1, R16.1; also elsewhere on the board
/KNOCK: C16.1, R11.1, R23.2; also elsewhere on the board
/LAUNCH: R14.1, R18.1; also elsewhere on the board
/TPS: C13.1, R15.1; also elsewhere on the board
/VSS: C17.1, R24.2, R82.1; also elsewhere on the board
Earth: C6.2, C7.2, C8.2, C9.2, C10.2, C11.2, C12.2, C13.2, C14.2, C15.2, C16.2, C17.2, C19.2, C20.1, C21.2, C22.2, C23.2, C24.1, C25.1, C45.2, C49.2, C50.2, D2.2 (GND), D3.2 (GND), D13.2 (GND), JP7.3 (B), JP8.3 (B), JP13.3 (B), JP14.3 (B), JP19.3 (B), R6.2, R20.1, U2.6 (GND), U2.8 (GND), U3.3 (GND); also elsewhere on the board
unnamed: C6.1, R2.2, R6.1, R7.1
unnamed: C20.2, J2.1, JP9.1 (A), R19.2, R20.2
unnamed: JP6.1 (A), R12.1
unnamed: JP6.3 (B), R3.1
unnamed: JP7.2 (C), R13.2
unnamed: JP8.2 (C), R14.2
unnamed: JP9.2 (B), U3.4 (Vout)
unnamed: JP13.2 (C), R5.2
unnamed: JP14.2 (C), R23.1
unnamed: JP19.2 (C), R24.1
unnamed: R1.1, U2.7 (VOUT)

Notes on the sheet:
VSS
Inlet Air Temp
Knock
Coolant Temp
Wide Band
Spare Analog 2
Battery Reference
Spare Analog 1
Flex Fuel
Baro Pres
Manifold Abs Pres
Launch
Throttle Position

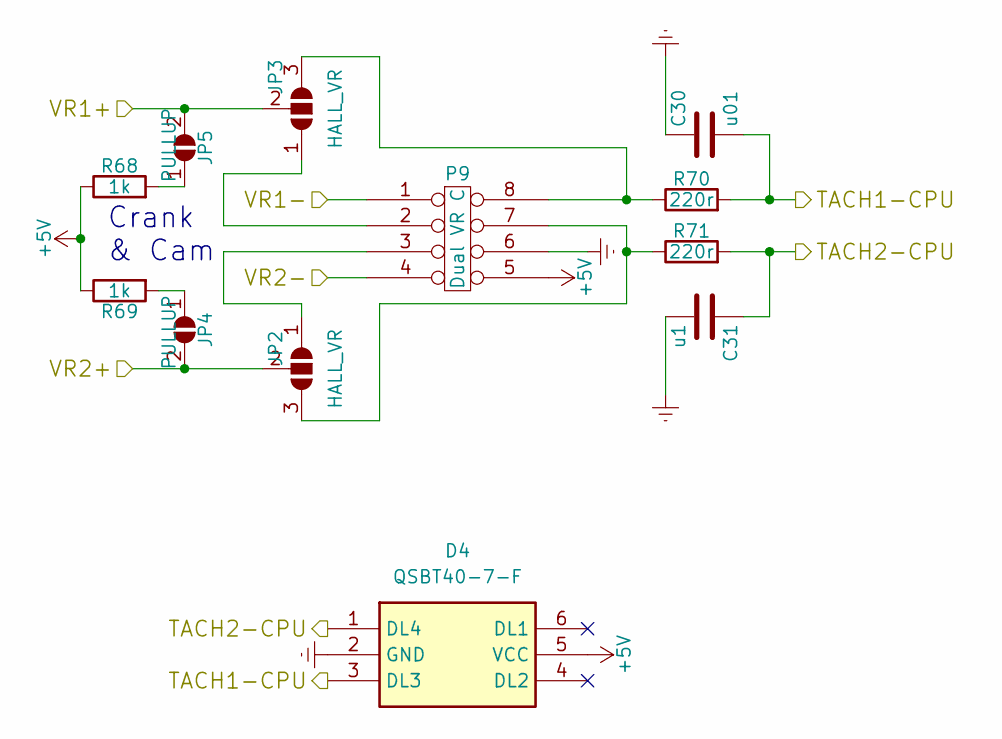
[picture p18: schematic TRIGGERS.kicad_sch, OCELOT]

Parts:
C30: u01; C_0603_1608Metric; MPN CL21B103KBCNNNC
C31: u1; C_0603_1608Metric; MPN CL21B104KBFNNNE
D4: QSBT40-7-F; SOT-363_SC-70-6; Mouser Part Number 621-QSBT40-F
JP2, JP3: HALL_VR; JPR_3POS_SMLHL; MPN DNP
JP4, JP5: PULLUP; JPR_2POS_SMLHL; MPN DNP
P9: Dual VR C; DIP-8_W7.62mm_Socket; MPN DNP
R68, R69: 1k; R_0603_1608Metric; MPN RK73H2ATTD1001F
R70, R71: 220r; R_0805_2012Metric; MPN RK73H2ATTD2200F

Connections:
+5V: D4.5 (VCC), P9.5, R68.1, R69.1; also elsewhere on the board
/D18: C31.1, D4.1 (DL4), R71.2; also elsewhere on the board
/D19: C30.2, D4.3 (DL3), R70.2; also elsewhere on the board
/RPM1: JP3.2 (C), JP5.2 (B); also elsewhere on the board
/RPM2: JP2.2 (C), JP4.2 (B); also elsewhere on the board
/VR1-: P9.1; also elsewhere on the board
/VR2-: P9.4; also elsewhere on the board
Earth: C30.1, C31.2, D4.2 (GND), P9.6; also elsewhere on the board
unnamed: JP2.1 (A), P9.3
unnamed: JP2.3 (B), P9.7, R71.1
unnamed: JP3.1 (A), P9.2
unnamed: JP3.3 (B), P9.8, R70.1
unnamed: JP4.1 (A), R69.2
unnamed: JP5.1 (A), R68.2

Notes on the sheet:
Crank & Cam

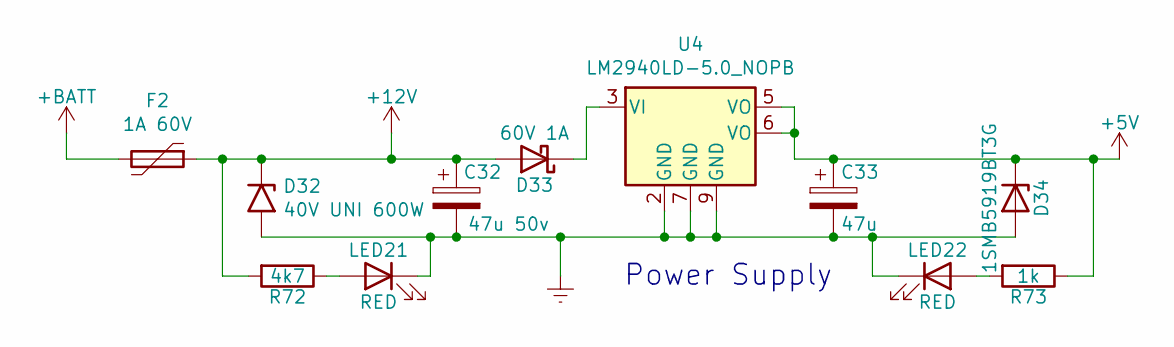
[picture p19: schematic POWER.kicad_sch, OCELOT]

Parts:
C32: 47u 50v; CP_Elec_6.3x5.4; MPN EEE-FT1H470AL
C33: 47u; CP_EIA-3216-18_Kemet-A; MPN T55A476M6R3C0200
D32: 40V UNI 600W; D_SMB; MPN SMBJ40A
D33: 60V 1A; D_SOD-123F; MPN SDM160S1FQ-7
D34: 1SMB5919BT3G; D_SMB; MPN 1SMB5919BT3G
F2: 1A 60V; Fuse_2920_7451Metric_Castellated; MPN 0ZCF0100AF2A
LED21, LED22: RED; LED_0402_1005Metric; MPN SML-310LTT86
R72: 4k7; R_0603_1608Metric
R73: 1k; R_0603_1608Metric; MPN RK73H2ATTD4700F
U4: LM2940LD-5.0_NOPB; WSON-8-1EP_4x4mm_P0.8mm_EP2.2x3mm_ThermalVias

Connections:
+5V: C33.1, D34.1 (K), R73.1, U4.5 (VO), U4.6 (VO); also elsewhere on the board
+12V: C32.1, D32.1 (A1), D33.2 (A), F2.1, R72.2; also elsewhere on the board
+BATT: F2.2; also elsewhere on the board
Earth: C32.2, C33.2, D32.2 (A2), D34.2 (A), LED21.1 (K), LED22.1 (K), U4.2 (GND), U4.7 (GND), U4.9 (GND); also elsewhere on the board
unnamed: D33.1 (K), U4.3 (VI)
unnamed: LED21.2 (A), R72.1
unnamed: LED22.2 (A), R73.2

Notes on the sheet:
Power Supply

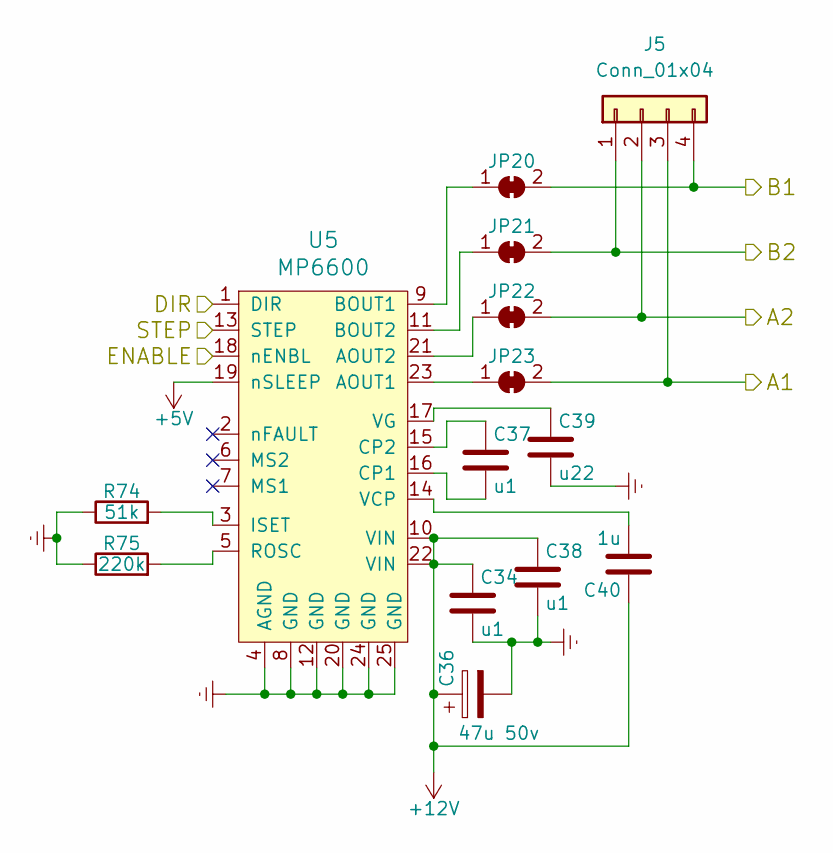
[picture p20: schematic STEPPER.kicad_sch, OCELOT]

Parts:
C34, C37, C38: u1; C_0603_1608Metric; MPN CL21B104KBFNNNE
C36: 47u 50v; CP_Elec_6.3x5.4; MPN EEE-FT1H470AL
C39: u22; C_0603_1608Metric; MPN CL21B224KBFNNNE
C40: 1u; C_0603_1608Metric; MPN CL21B105KBFNNNE
J5: Conn_01x04; PinHeader_1x04_P2.00mm_Vertical
JP20, JP21, JP22, JP23: FB CONTROL; SolderJumper-2_P1.3mm_Bridged_Pad1.0x1.5mm_VisibleBridge; MPN DNP
R74: 51k; R_0402_1005Metric; MPN RK73H2ATTD5102F
R75: 220k; R_0402_1005Metric; MPN RK73H2ATTD2203F
U5: MP6600; QFN-24-1EP_4x4mm_P0.5mm_EP2.7x2.7mm_ThermalVias; MPN MP6600GR-Z

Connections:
+5V: U5.19 (nSLEEP); also elsewhere on the board
+12V: C34.1, C36.1, C38.1, C40.1, U5.10 (VIN), U5.22 (VIN); also elsewhere on the board
/DIR: U5.1 (DIR); also elsewhere on the board
/ENBL: U5.18 (nENBL); also elsewhere on the board
/STEP: U5.13 (STEP); also elsewhere on the board
/STP-A1: J5.3, JP23.2 (B); also elsewhere on the board
/STP-A2: J5.2, JP22.2 (B); also elsewhere on the board
/STP-B1: J5.4, JP20.2 (B); also elsewhere on the board
/STP-B2: J5.1, JP21.2 (B); also elsewhere on the board
Earth: C34.2, C36.2, C38.2, C39.2, R74.1, R75.1, U5.4 (AGND), U5.8 (GND), U5.12 (GND), U5.20 (GND), U5.24 (GND), U5.25 (GND); also elsewhere on the board
unnamed: JP20.1 (A), U5.9 (BOUT1)
unnamed: JP21.1 (A), U5.11 (BOUT2)
unnamed: JP22.1 (A), U5.21 (AOUT2)
unnamed: JP23.1 (A), U5.23 (AOUT1)
unnamed: C37.2, U5.16 (CP1)
unnamed: C37.1, U5.15 (CP2)
unnamed: R74.2, U5.3 (ISET)
unnamed: R75.2, U5.5 (ROSC)
unnamed: C40.2, U5.14 (VCP)
unnamed: C39.1, U5.17 (VG)

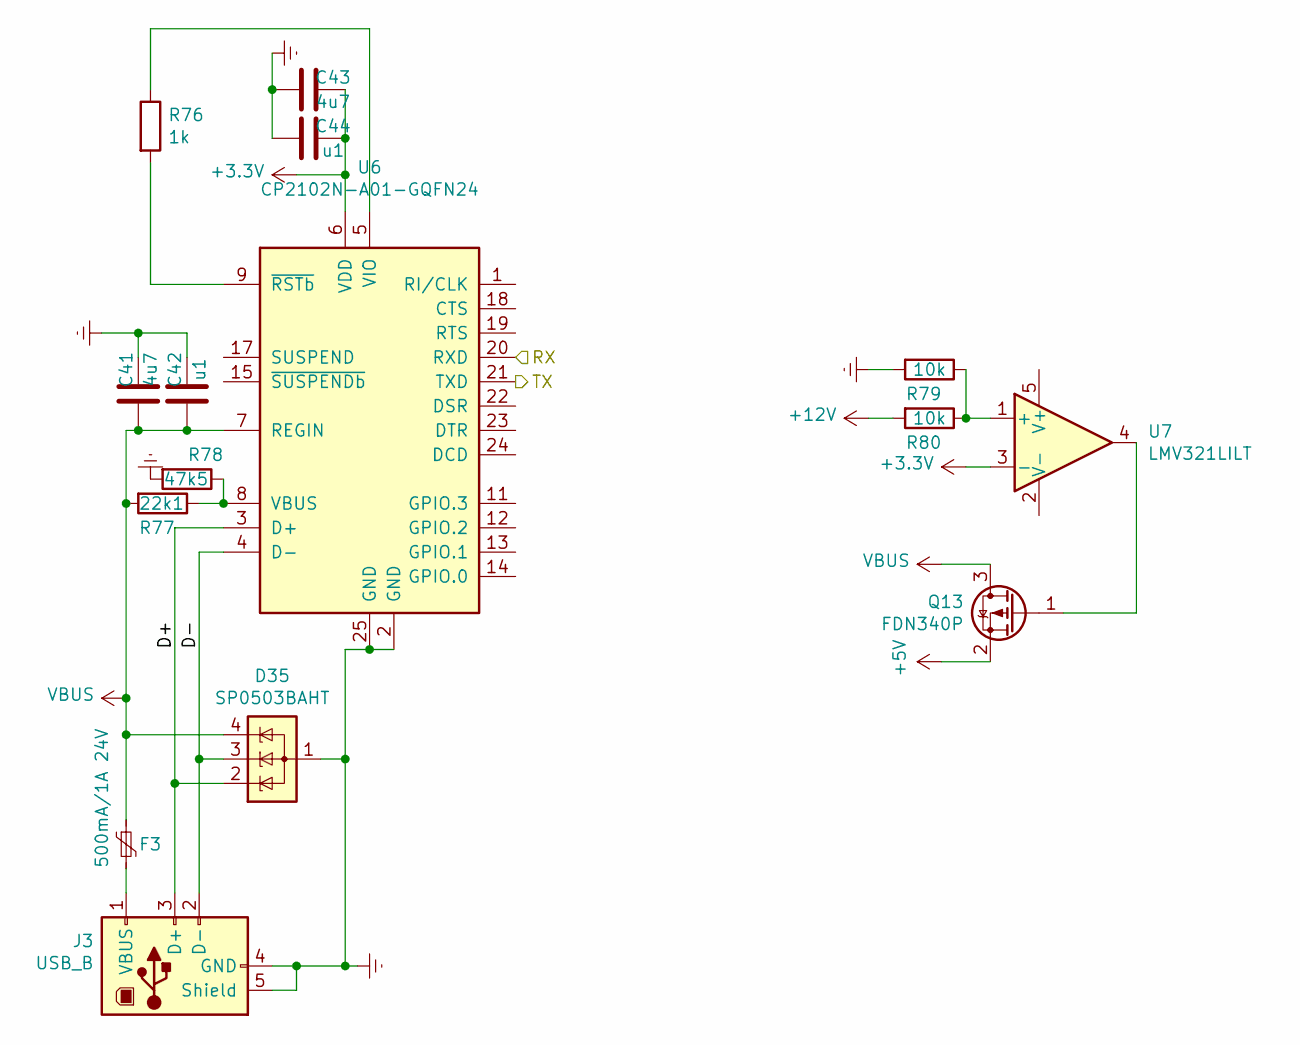
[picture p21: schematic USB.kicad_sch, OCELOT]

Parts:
C41, C43: 4u7; C_0603_1608Metric
C42, C44: u1; C_0603_1608Metric
D35: SP0503BAHT; SOT-143
F3: 500mA/1A 24V; Fuse_1206_3216Metric; MPN 0ZCJ0050AF2E
J3: USB_B; USB_B_JST_UBB-4R-D14T-4D_Horizontal
Q13: FDN340P; SOT-23
R76: 1k; R_0603_1608Metric
R77: 22k1; R_0402_1005Metric
R78: 47k5; R_0402_1005Metric
R79, R80: 10k; R_0603_1608Metric
U6: CP2102N-A01-GQFN24; QFN-24-1EP_4x4mm_P0.5mm_EP2.6x2.6mm_ThermalVias
U7: LMV321LILT; SOT-23-5

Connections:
+3V3: C43.1, C44.1, U6.6 (VDD), U7.3 (-)
+5V: Q13.2 (S); also elsewhere on the board
+12V: R80.2; also elsewhere on the board
/RX0: U6.21 (TXD); also elsewhere on the board
/TX0: U6.20 (RXD); also elsewhere on the board
/USB/D+: D35.2 (K), J3.3 (D+), U6.3 (D+)
/USB/D-: D35.3 (K), J3.2 (D-), U6.4 (D-)
Earth: C41.1, C42.1, C43.2, C44.2, D35.1 (A), J3.4 (GND), J3.5 (Shield), R78.2, R79.2, U6.2 (GND), U6.25 (GND); also elsewhere on the board
unnamed: F3.2, J3.1 (VBUS)
unnamed: Q13.1 (G), U7.4
unnamed: R77.1, R78.1, U6.8 (VBUS)
unnamed: R76.1, U6.5 (VIO)
unnamed: R76.2, U6.9 (~RSTb)
unnamed: R79.1, R80.1, U7.1 (+)
VBUS: C41.2, C42.2, D35.4 (K), F3.1, Q13.3 (D), R77.2, U6.7 (REGIN)

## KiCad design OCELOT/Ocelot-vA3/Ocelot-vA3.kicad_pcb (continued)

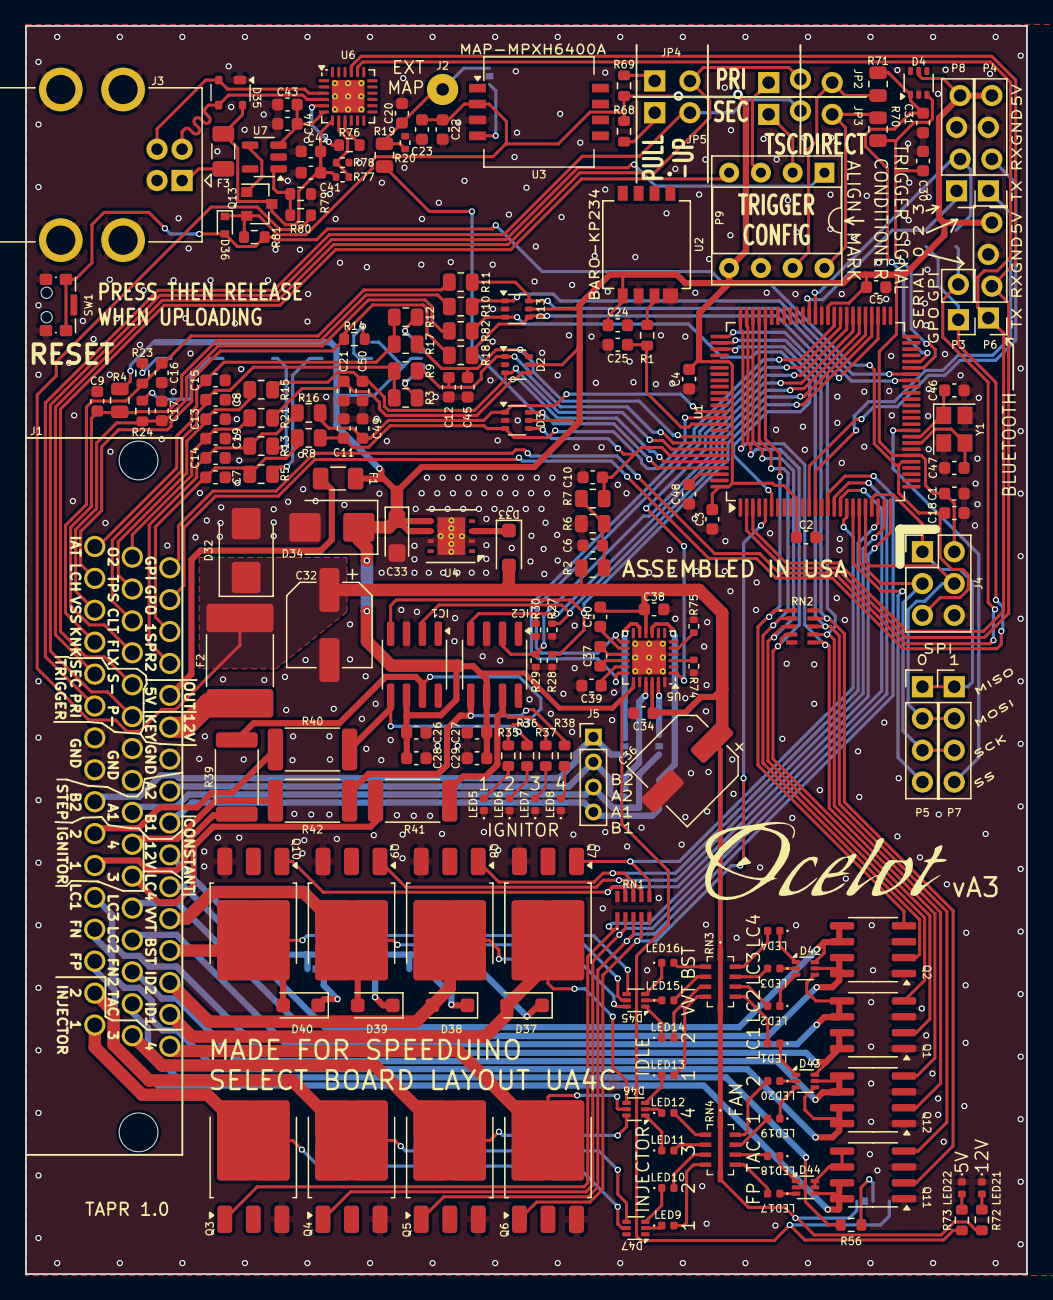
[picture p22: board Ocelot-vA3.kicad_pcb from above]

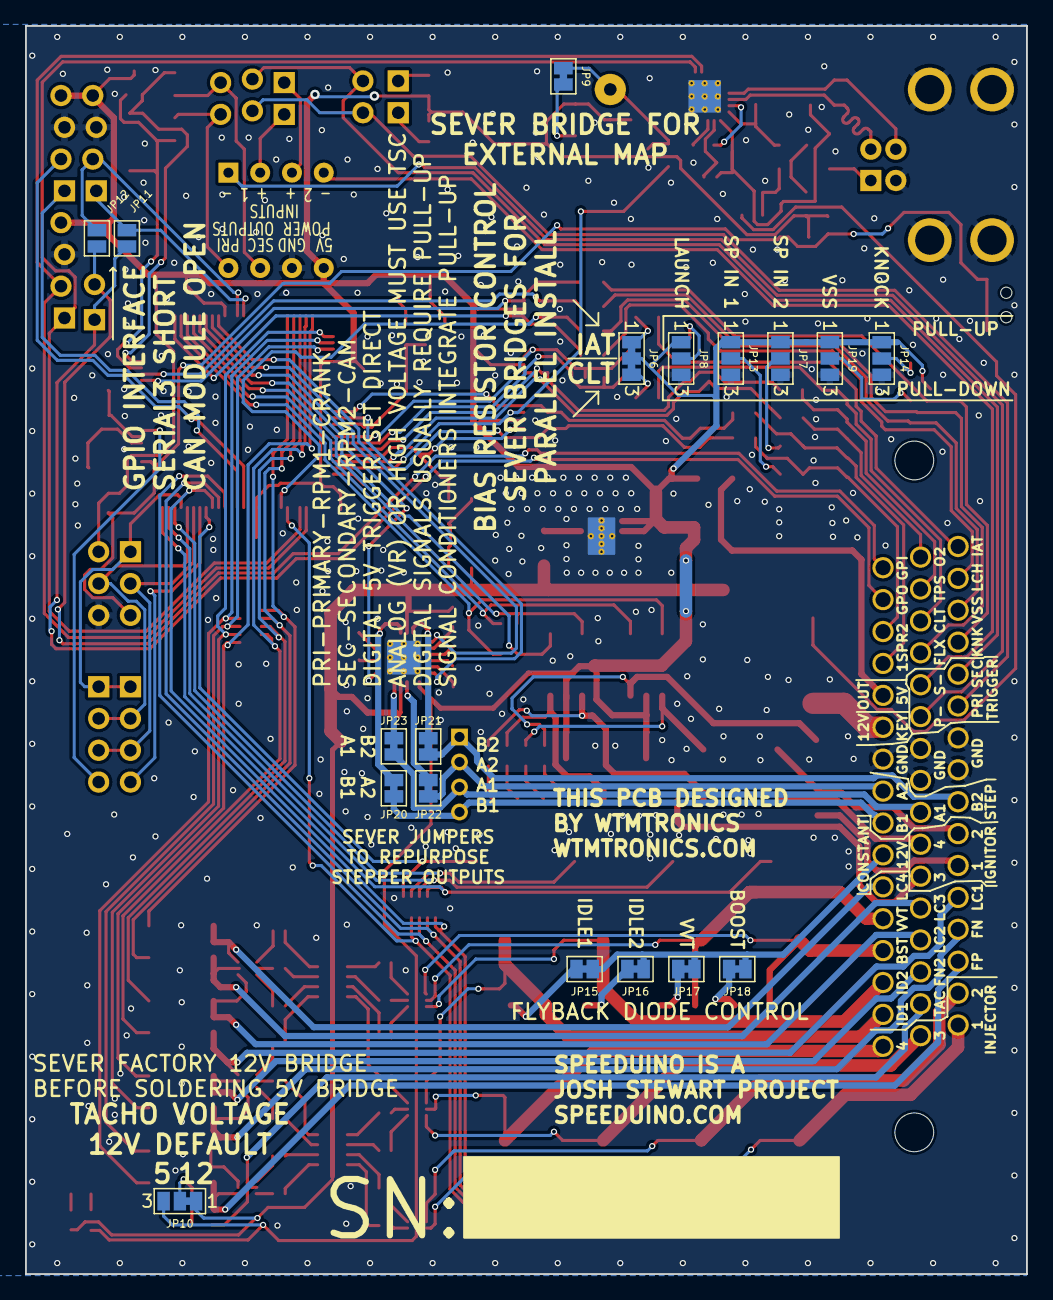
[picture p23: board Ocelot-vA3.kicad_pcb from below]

Board: 2 copper layers, 80.0 x 99.8 mm, 206 parts (18 on the bottom side), 185 nets.
